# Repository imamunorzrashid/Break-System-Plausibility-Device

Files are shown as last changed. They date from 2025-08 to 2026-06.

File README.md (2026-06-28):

# Brake System Plausibility Device (BSPD)

A standalone, analog **Brake System Plausibility Device (BSPD)** designed for **Formula Student / Formula SAE Electric Vehicles**. This project implements the mandatory BSPD safety system using analog comparators, logic gates, and timing circuits without relying on programmable controllers.

The BSPD continuously monitors the brake pressure sensor and tractive system current sensor. If hard braking occurs while the vehicle is delivering significant propulsion power, or if either sensor fails, the BSPD opens the Shutdown Circuit (SDC), disabling the tractive system.

---

## Features

- Standalone non-programmable hardware implementation
- Analog signal conditioning using LM358 op-amps
- Brake pressure and tractive current monitoring
- Adjustable sensor thresholds
- Sensor fault detection (Open Circuit / Short Circuit)
- 500 ms plausibility timer
- Direct Shutdown Circuit (SDC) control
- Designed according to Formula Student / Formula SAE BSPD requirements

---

## Repository Structure

```
.
├── BSPD.kicad_sch      # KiCad schematic
├── BSPD.kicad_pcb      # PCB layout
├── BSPD.kicad_pro
├── BSPD.kicad_prl
├── Bspd updated.pdf    # Schematic PDF
├── BSPD-backups/
└── README.md
```

---

# System Overview

The BSPD consists of four major functional blocks:

1. Signal Conditioning
2. Sensor Validation
3. Plausibility Detection
4. Shutdown Circuit Control

---

# Circuit Operation

## 1. Signal Conditioning

The brake pressure sensor and current sensor produce analog voltages proportional to brake pressure and tractive system current.

LM358 operational amplifiers (U1A and U1B) are configured as comparators to condition these signals and compare them against adjustable reference voltages.

The comparator output becomes HIGH whenever:

```
Sensor Voltage > Reference Voltage
```

This indicates:

- Hard braking detected
- Tractive system current corresponding to approximately **5 kW** or greater

The reference voltages can be adjusted using onboard potentiometers to calibrate the BSPD.

---

## 2. Sensor Validation

Sensor failures such as broken wires or short circuits can produce invalid voltages.

To detect these faults, each sensor is monitored using window comparators (U3A and U3B).

The valid operating range is:

```
0.5 V < Sensor Voltage < 4.5 V
```

Therefore,

- Voltage below **0.5 V**
  - Short to Ground
  - Open sensor
  - Broken wire

- Voltage above **4.5 V**
  - Short to Supply
  - Sensor failure

Only signals within the valid operating window are considered acceptable.

If either sensor voltage falls outside this range, the BSPD immediately opens the Shutdown Circuit.

---

## 3. Plausibility Detection

The conditioned outputs from the pressure and current comparators are connected to a **74HC08 AND gate (U2)**.

The AND gate confirms that both conditions occur simultaneously:

- Hard braking
- Current equivalent to ≥ 5 kW

Mathematically,

```
Brake AND Current
```

To prevent nuisance trips caused by noise or transient conditions, this signal passes through a **555 Timer** configured to introduce a **500 ms delay**.

The BSPD only considers the event valid if both signals remain HIGH continuously for at least **0.5 seconds**.

---

## 4. Shutdown Logic

A **74V1G27 NOR gate (U5)** controls the Shutdown Circuit (SDC).

The NOR gate monitors:

- Pressure sensor validity
- Current sensor validity
- 500 ms plausibility signal

The Shutdown Circuit opens whenever:

- Either sensor experiences an open circuit
- Either sensor experiences a short circuit
- Both plausibility conditions are not continuously satisfied for 500 ms

This immediately disables the tractive system by opening the SDC.

---

# Logic Summary

| Brake | Current | Sensor Status | Delay | BSPD Action |
|---|---|---|---|---|
| No | No | Valid | — | Normal |
| Yes | No | Valid | — | Normal |
| No | Yes | Valid | — | Normal |
| Yes | Yes | Valid | <500 ms | Normal |
| Yes | Yes | Valid | ≥500 ms | Open SDC |
| Any | Any | Open Circuit | — | Open SDC |
| Any | Any | Short Circuit | — | Open SDC |

---

# Hardware Components

| Component | Description |
|---|---|
| LM358 | Signal conditioning comparators |
| LM358 | Window comparator for fault detection |
| 74HC08 | AND logic gate |
| 74V1G27 | NOR gate for shutdown logic |
| NE555 | 500 ms delay timer |
| Potentiometers | Threshold adjustment |
| Passive Components | Filters, references, pull-ups and timing network |

---

# Formula Student / Formula SAE Compliance

This BSPD has been designed around the requirements specified in:

- Formula SAE Rules 2025
- Formula Student Rules 2026

Implemented requirements include:

- Standalone non-programmable circuit
- Independent brake and current sensing
- Detection of simultaneous hard braking and ≥5 kW power
- Maximum 500 ms response time
- Open circuit detection
- Short circuit detection
- Direct Shutdown Circuit activation

---

# Future Improvements

- Manual reset latch
- Improved EMC filtering
- Automotive-grade connectors
- ISO 26262-inspired diagnostic coverage
- LED status indicators
- Hardware redundancy

---

# Software

No firmware or programmable controller is required.

All safety logic is implemented entirely in hardware.

---

# PCB

The PCB was designed in **KiCad** and includes:

- Analog signal conditioning
- Sensor validation circuitry
- Logic gate implementation
- Delay timer
- Shutdown interface

---

# Author

**Mamun Or Rashid**

Mechatronics Engineering  
Rajshahi University of Engineering & Technology (RUET)

GitHub:
https://github.com/imamunorzrashid

---

# License

This project is released under the MIT License.

Feel free to use, modify, and improve this design for educational and Formula Student projects.

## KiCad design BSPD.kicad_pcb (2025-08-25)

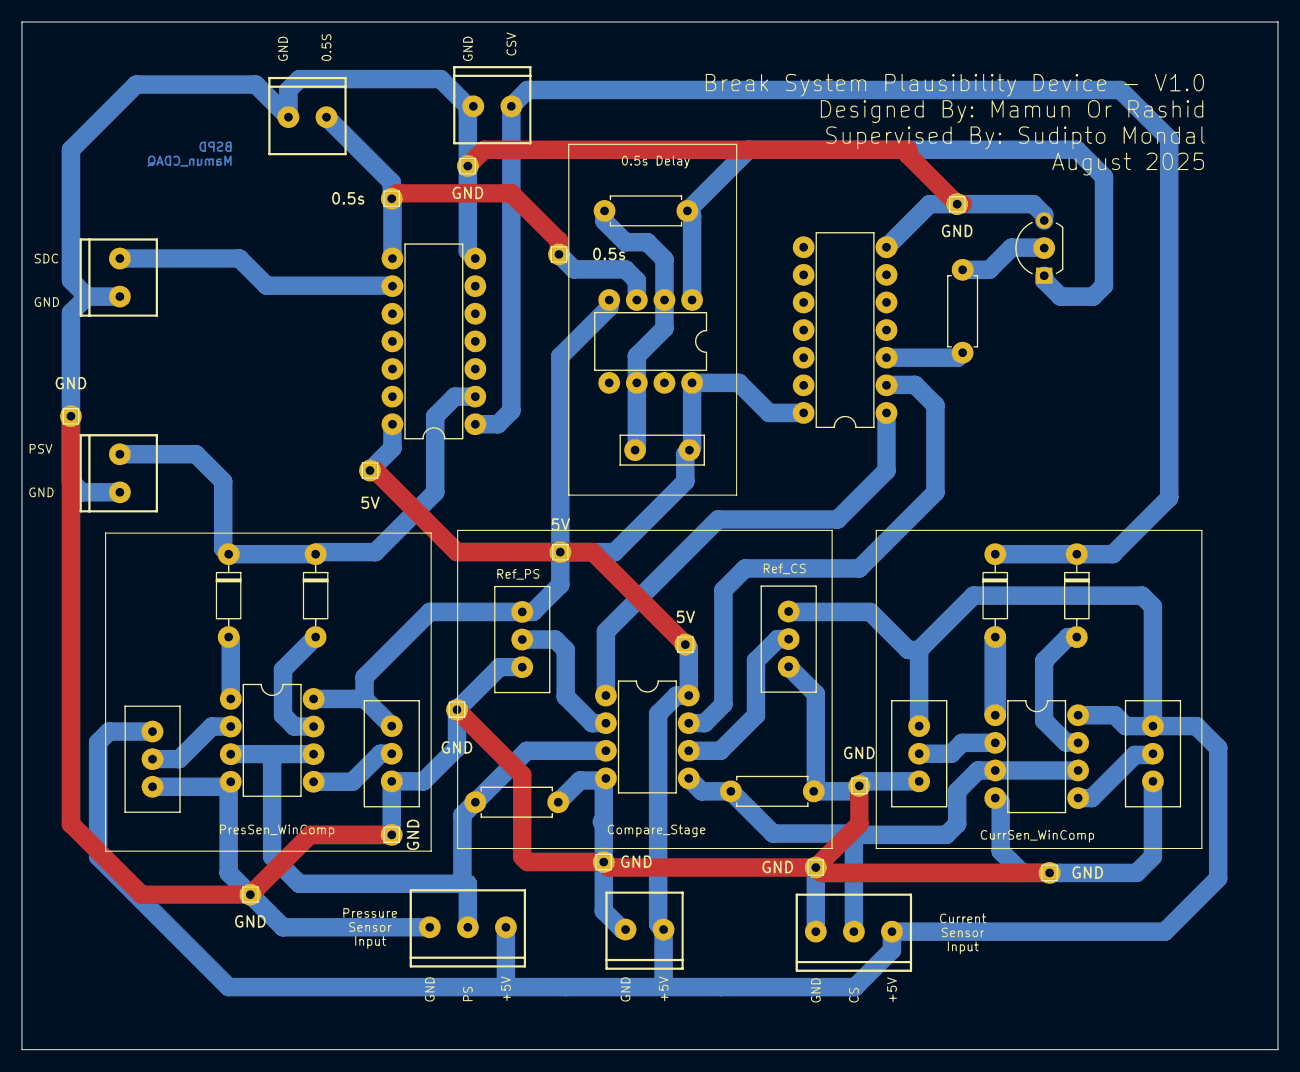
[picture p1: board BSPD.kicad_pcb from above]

Board: 2 copper layers, 115.5 x 94.5 mm, 44 parts (0 on the bottom side), 24 nets.

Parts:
0.5s, 0.5s#2, 5V, 5V#2, 5V#3: TestPoint_THTPad_1.0x1.0mm_Drill0.5mm
C3: 10uF; C_Disc_D7.5mm_W2.5mm_P5.00mm
D1, D2, D3, D4: D; D_DO-35_SOD27_P7.62mm_Horizontal
GND: TestPoint_THTPad_1.0x1.0mm_Drill0.5mm
GND#2, GND#3, GND#4, GND#5, GND#6, GND#7, GND#8, GND#9, GND#10: TestPoint_THTPad_1.0x1.0mm_Drill0.5mm
J1, J2, J5, J6, J7: Screw_Terminal_3.5mm_2; Screw_Terminal_3.5mm-2
J3, J4: Screw_Terminal_3.5mm_3; Screw_Terminal_3.5mm-3
Q3: NPN; TO-92L_Inline_Wide
R1, R2, R21: 1k; R_Axial_DIN0207_L6.3mm_D2.5mm_P7.62mm_Horizontal
R4: 45.5k; R_Axial_DIN0207_L6.3mm_D2.5mm_P7.62mm_Horizontal
RV1, RV2: 10k; Potentiometer_Bourns_3296W_Vertical
RV3, RV4, RV5, RV6: 1k; Potentiometer_Bourns_3296W_Vertical
U1, U2, U6: LM358; DIP-8_W7.62mm
U3: 4075; DIP-14_W7.62mm
U4: LM555xN; DIP-8_W7.62mm
U7: SN74LS08N; DIP-14_W7.62mm

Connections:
+5V: 5V.1, 5V#2.1, 5V#3.1, C3.2, J3.3, J4.3, J7.2, RV1.1, RV2.1, RV3.1, RV4.1, RV5.1, RV6.1, U1.8 (V+), U2.8 (V+), U3.14 (VDD), U4.4 (R), U4.8 (VCC), U6.8 (V+), U7.14 (VCC)
/0.5s_delay: 0.5s.1, 0.5s#2.1, J5.1, U3.8, U4.3 (Q)
/2: C3.1, R4.2, U4.2 (TR), U4.6 (THR)
/Current_Comp_Out: U6.7, U7.2 (1B)
/Current_Sensor: J3.2, R2.1, U1.3 (+), U1.6 (-), U6.5 (+)
/Current_Sensor_Validated: D1.1 (K), D2.1 (K), J6.1, U3.1
/Pressure_Comp_Out: U6.1, U7.1 (1A)
/Pressure_Sensor: J4.2, R1.1, U2.3 (+), U2.6 (-), U6.3 (+)
/Pressure_Sensor_Validated: D3.1 (K), D4.1 (K), J2.1, U3.2
/SDC: J1.1, U3.9
GND: GND.1, GND#2.1, GND#3.1, GND#4.1, GND#5.1, GND#6.1, GND#7.1, GND#8.1, GND#9.1, GND#10.1, J1.2, J2.2, J3.1, J4.1, J5.2, J6.2, J7.1, Q3.3 (E), R1.2, R2.2, RV1.3, RV2.3, RV3.3, RV4.3, RV5.3, RV6.3, U1.4 (V-), U2.4 (V-), U3.7 (VSS), U6.4 (V-), U7.7 (GND)
unnamed: D1.2 (A), U1.1
unnamed: D2.2 (A), U1.7
unnamed: D3.2 (A), U2.1
unnamed: D4.2 (A), U2.7
unnamed: Q3.2 (B), R21.2
unnamed: Q3.1 (C), R4.1, U4.1 (GND)
unnamed: RV3.2, U1.2 (-)
unnamed: RV4.2, U1.5 (+)
unnamed: RV6.2, U2.2 (-)
unnamed: RV5.2, U2.5 (+)
unnamed: RV1.2, U6.2 (-)
unnamed: RV2.2, U6.6 (-)
unnamed: R21.1, U7.3 (1Y)

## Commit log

2025-07-31 commited - 01 August 2025
    [BSPD.kicad_pcb, BSPD.kicad_sch]
2025-07-31 Text Added
    [BSPD.kicad_pcb]
2025-07-31 Rounded PCB
    [BSPD.kicad_pcb]
2025-07-31 Final Commit for print
    [BSPD.kicad_pcb]
2025-07-31 Solid Zone Added
    [BSPD.kicad_pcb]
2025-08-25 updated pcb with better clearance
    [BSPD.kicad_pcb, BSPD.kicad_sch]
2026-06-28 Add README for Brake System Plausibility Device
    Add detailed documentation for the Brake System Plausibility Device (BSPD), including features, system overview, circuit operation, hardware components, compliance, and future improvements.
2026-06-28 Create README.md for BSPD project
    Add detailed documentation for the Brake System Plausibility Device (BSPD), including features, system overview, circuit operation, hardware components, compliance, future improvements, and author in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
